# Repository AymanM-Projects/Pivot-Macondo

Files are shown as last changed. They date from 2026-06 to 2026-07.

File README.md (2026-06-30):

# Pivot-Macondo

What I created is a motorized mount that holds my friend's camera on a tripod so a person standing far away can point it, zoom it, and hit record all wirelessly from a controller, without ever touching the camera.

The reason I actually started this project is that I really wanted to create something with new CAD and coding skulls and really start using these skills to create  something meaningful, but  why I decided to create this mount specifically is for my childhood friend. I've known him for ten years. He's grown this passion for  cameras, photography, and videography, and I have noticed how he has enjoyed it when he does it. He uses cameras to make stories, to help people, we do advocacy. I thought it would be amazing for me and him to combine our talents and our passions, because I want to do the same thing.

What really matters to me is that I can actually use what I'm good at to create something with strength behind it. I want to create, I love making things, not just for myself, and not for money, but things that actually matter to people and make a real difference in their lives. I don't want anything in return for this. I just want to see people happy.

And I don't want this to be the end, I want it to be the start. Creativity can go a lot of ways. For me it's coding and hardware. But not just making things,  making new inventions. Creating products. Not just products, but inventions and innovations that change people's lives. That's why I'm starting here, with something I have a real passion to work on. I saw this kind of technology  and I knew I could make it the moment I saw it.

For the actual technical components I used **Onshape** for modeling and my **Bambu P2S** for test prints.

The mount contains 3 main components:
1. A Panning mechanism powered by a nema 17 stepper motor that is at the bottom and will rotate the hole mount 360 degrees 
2. A tilting mechanism that uses another nema 17 but also a bearing and a metal rod that goes through the drive and idle arms, it should rotate the entire camera cage 90 degrees vertically.
3. Lastly a zoom feature that works with a Pinion Motor gear  and a focus ring and a 28BYJ-48  for zooming the camera

Some additional things:
-  Through this project I learned a lot about clearance and how 3dc printing warps holes Before I thought you could design with exact parameters for each design but now i realize that you need to add clearance values for certain structures/features
- I learned what a driver is and how it works with a stepper motor
- I learned how to do torque math, for my two spinning motors(pan/tilt)

Things I want to do in the future:
- Right now It only fits my friends camera and fits for his tripod but i want to make it so it is like a phone holder and you can basically connect it to any camera through a slider or springs
- I want to add a way for users to make it go horizontal and vertical on a slider with a another motor because i feel this can be more useful
- I want to try using more gears or getting the price down for future builds
- 
## BOM

| Subsystem | Item | Purpose | Price | Source |
| --- | --- | --- | --- | --- |
| Pan mechanism | Lazy Susan Bearing 4 inch | Carries the rotating pan load (bearing takes the weight, not the motor shaft) | $4.99 | [Amazon](https://www.amazon.com/Turntable-Bearing-Rotating-Cabinet-Profile/dp/B09V2S71J1) |
| Pan mechanism | TMC2209 V1.3 Stepper Motor Driver (6-pack) | Drives a stepper motor quietly with current control | $29.99 | [Amazon](https://www.amazon.com/BIGTREETECH-Direct-TMC2209-Stepper-Control/dp/B08WZFK9KT) |
| Pan mechanism | NEMA 17 Stepper Motor (MAKERELE, 42-40mm) | Direct-drive pan axis rotation | $12.99 | [Amazon](https://www.amazon.com/MAKERELE-Stepper-42-48mm-Connector-Printers/dp/B0FP1QQ1NT) |
| Tilt mechanism | NEMA 17 Stepper Motor L=39mm 10:1 Planetary Gearbox | Geared tilt axis drive (holds the camera against gravity) | $37.99 | [Amazon](https://www.amazon.com/STEPPERONLINE-Nema-Stepper-Motor-Ratio/dp/B0F4CKD1VC) |
| Tilt mechanism | 608ZZ Ball Bearing (10 pcs) | Supports the tilt pivot shaft | $4.87 | [Amazon](https://www.amazon.com/Bearings-Double-Shielded-Miniature-Skateboard/dp/B07H83VV6B) |
| Tilt mechanism | 8mm dia 300mm 304 SS Round Rod (2 pcs) | Tilt pivot shaft + zoom support rod (cut to length) | $11.99 | [Amazon](https://www.amazon.com/Etauwe-Diameter-Length-Stainless-Working/dp/B0G78Y8HB4) |
| Tilt mechanism | 8mm Shaft Lock Collar (10 pcs) | Locks shafts axially in place | $8.89 | [Amazon](https://www.amazon.com/Zeberoxyz-Stainless-Material-Isolation-Accessories/dp/B08SK2LNNV) |
| Zoom mechanism | M3 M4 M5 Screws & Nuts Assortment Kit (460 pcs) | General fasteners across all assemblies | $13.49 | [Amazon](https://www.amazon.com/Hilitchi-510pcs-Stainless-Socket-Assortment/dp/B06XRFKNPQ) |
| Zoom mechanism | 0.8M 5mm Pinion Motor Gear 11T (3 pcs) | Steel pinion meshes with the lens gear ring to drive zoom | $9.99 | [Amazon](https://www.amazon.com/Fraizoe-RC-0-8M-5mm-3Pcs/dp/B0DYK2Z85B) |
| Zoom mechanism | 28BYJ-48 ULN2003 5V Stepper Motor (5 sets) | Drives the zoom ring with repeatable position | $14.99 | [Amazon](https://www.amazon.com/ELEGOO-28BYJ-48-ULN2003-Stepper-Arduino/dp/B01CP18J4A) |
| Zoom mechanism | SmallRig Seamless Gear Ring (72mm–74mm) | Rubber gear ring grips lens zoom barrel (removable, no marring) | $2.99 | [Amazon](https://www.amazon.com/SmallRig-Seamless-Focus-Gear-Ring/dp/B0986XSTP4) |
| Battery/wiring | AITRIP ESP32 30-pin USB-C (3-pack + expansion boards) | Microcontrollers for mount + controller (ESP-NOW link) | $9.99 | [Amazon](https://www.amazon.com/dp/B0B82CKB1K) |
| Battery/wiring | Anker Nano Power Bank 10000mAh 30W | Portable power source for the mount | $49.99 | [Amazon](https://www.amazon.com/Anker-Portable-Charger-Compatible-MacBook/dp/B0C9CJKCH3) |
| Battery/wiring | ACEIRMC ZY12PDN PD Trigger (2-pack screw terminals) | Pulls fixed 12V from the bank for the stepper rail | $14.99 | [Amazon](https://www.amazon.com/dp/B0CNVQMP6C) |
| Prototyping | ELEGOO 830-Point Solderless Breadboard (3 pcs) | Solderless prototyping of control/trigger circuits | $8.99 | [Amazon](https://www.amazon.com/EL-CP-003-Breadboard-Solderless-Distribution-Connecting/dp/B01EV6LJ7G) |
| Prototyping | ELEGOO 120pc Dupont Jumper Wires (M/M + M/F + F/F) | Breadboard interconnects in all three pin genders | $6.98 | [Amazon](https://www.amazon.com/Elegoo-EL-CP-004-Multicolored-Breadboard-arduino/dp/B01EV70C78) |
| Camera trigger | NOYITO PC817 1-Channel Optocoupler Module (screw terminals; 2-pack) | Isolated shutter signal, no electrical connection to the borrowed camera | $6.99 | [Amazon](https://www.amazon.com/NOYITO-1-Channel-Optocoupler-Optoelectronic-Anti-Interference/dp/B0B537T73S) |
| Camera trigger | CablesOnline 2.5mm TRS Male to 3-Pole Screw Terminal Connector (5-pack) | Plugs into S5ii remote port for shutter/record (verify pinout before wiring) | $16.95 | [Amazon](https://www.amazon.com/CablesOnline-3-Screw-Terminal-Connectors-PL-CN22-5/dp/B01J4JLP6K) |
| Power/filtering | ALLECIN 24-Value Electrolytic Capacitor Assortment Kit | Incl. 100uF/220uF/470uF — one cap across each driver VM absorbs spikes | $9.99 | [Amazon](https://www.amazon.com/ALLECIN-Electrolytic-Capacitor-Assortment-Kit/dp/B0C1VBXCQM) |
| Control input | 8BitDo SN30 Pro Bluetooth Gamepad | Bluepad32-compatible name-brand controller for the gamepad path | $44.99 | [Amazon](https://www.amazon.com/Bluetooth-Controller-Compatible-Raspberry-Gaming-Console/dp/B0CSP6TTJJ) |
| Filament | Black PETG Filament (1kg spool) | Structural printed parts (brackets, cradle, column) | $19.00 | [Bambu Lab](https://us.store.bambulab.com/products/petg-hf) |
| Tools | Onshape | CAD modeling | Owned (free) | |
| Tools | Bambu P2S 3D Printer | Manufactures the printed parts | Owned | |
| Tools | Arca Quick-Release Clamp | Tripod connection (already owned) | Owned | |
| ------------- | ------------- | ------------- | ------------- | ------------- |
| | | | | **Total: $342.03** |

# CAD
The link to my onshape document: https://cad.onshape.com/documents/704bc5fe6bc4690c89ce2bf7/w/60606dae933200bf2d7a1e9c/e/83d6a801d920139ae14113a5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

### Individual Parts:
quick release clamp(for connecting to the camera cage)



panning mechnism(connects to tripod and holds motor)



holder for camera cage w motor box for tilt motor


zoom(holder for the zoom motor and pinion gear to connect to the rest of the mount)



### Assembly 



## What's in this repo
- [CAD — my designed parts (STEP files)](cad/My_parts)
- [CAD — imported reference models + GrabCAD links](cad/Imports/intro.md)
- [Wiring diagram (EasyEDA)](Electronics/wiringdiagram.md)
- [Bill of Materials](BOM.csv)

Refrence(inspiration):https://github.com/geg-tech/biblicallyaccuratekeyboard/blob/main/README.md - I liked the format and the friendly tone,

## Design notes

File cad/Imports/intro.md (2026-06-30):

# Imported Parts (GrabCAD)

Here are all the GrabCAD models I used in my Onshape assembly. **None of these are my own designs** they're off-the-shelf parts I downloaded only as reference, so I could model and fit my own printed parts around them. Full credit goes to the original GrabCAD creators.

## Pan mechanism

- **Lazy Susan bearing (4"):** https://grabcad.com/library/4-inch-lazy-susan-turntable-steel-ball-bearing-rotating-tray-table-1
- **NEMA 17 stepper motor (pan axis):** https://grabcad.com/library/steeper-motor-nema-17-1

## Tilt mechanism

- **NEMA 17 stepper + 10:1 planetary gearbox (tilt axis):** https://www.omc-stepperonline.com/mg-series-planetary-gearbox-gear-ratio-10-1-backlash-30-arc-min-for-nema-17-stepper-motor-mg17-g10
- **608ZZ ball bearing:** https://grabcad.com/library/608zz-bearing-cad-model-with-exploded-assembly-and-technical-drawing-1
- **8mm shaft lock collar:** https://grabcad.com/library/8mm-internal-diameter-shaft-collar-lock-collar-1

## Zoom mechanism

- **28BYJ-48 stepper motor:** https://grabcad.com/library/28byj-48-8

## Other (not GrabCAD)
- **1/4-20 tripod nut/screw (tripod connector)** — from Cults3D: https://cults3d.com/en/3d-model/gadget/1-4-20-nut-screw-for-photo-camera-mount

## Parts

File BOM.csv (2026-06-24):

Subsystem | Item | Purpose | Qty | Price (USD) | Source
Pan mechanism | Lazy Susan Bearing 4 inch | Carries the rotating pan load (bearing takes the weight not the motor shaft) | 1 | 4.99 | https://www.amazon.com/Turntable-Bearing-Rotating-Cabinet-Profile/dp/B09V2S71J1
Pan mechanism | TMC2209 V1.3 Stepper Motor Driver (6-pack) | Drives a stepper motor quietly with current control | 1 | 29.99 | https://www.amazon.com/BIGTREETECH-Direct-TMC2209-Stepper-Control/dp/B08WZFK9KT
Pan mechanism | NEMA 17 Stepper Motor (MAKERELE 42-40mm) | Direct-drive pan axis rotation | 1 | 12.99 | https://www.amazon.com/MAKERELE-Stepper-42-48mm-Connector-Printers/dp/B0FP1QQ1NT
Tilt mechanism | NEMA 17 Stepper Motor L=39mm 10:1 Planetary Gearbox | Geared tilt axis drive (holds the camera against gravity) | 1 | 37.99 | https://www.amazon.com/STEPPERONLINE-Nema-Stepper-Motor-Ratio/dp/B0F4CKD1VC
Tilt mechanism | 608ZZ Ball Bearing (10 pcs) | Supports the tilt pivot shaft | 1 | 4.87 | https://www.amazon.com/Bearings-Double-Shielded-Miniature-Skateboard/dp/B07H83VV6B
Tilt mechanism | 8mm dia 300mm 304 SS Round Rod (2 pcs) | Tilt pivot shaft + zoom support rod (cut to length) | 1 | 11.99 | https://www.amazon.com/Etauwe-Diameter-Length-Stainless-Working/dp/B0G78Y8HB4
Tilt mechanism | 8mm Shaft Lock Collar (10 pcs) | Locks shafts axially in place | 1 | 8.89 | https://www.amazon.com/Zeberoxyz-Stainless-Material-Isolation-Accessories/dp/B08SK2LNNV
Zoom mechanism | M3 M4 M5 Screws & Nuts Assortment Kit (460 pcs) | General fasteners across all assemblies | 1 | 13.49 | https://www.amazon.com/Hilitchi-510pcs-Stainless-Socket-Assortment/dp/B06XRFKNPQ
Zoom mechanism | 0.8M 5mm Pinion Motor Gear 11T (3 pcs) | Steel pinion meshes with the lens gear ring to drive zoom | 1 | 9.99 | https://www.amazon.com/Fraizoe-RC-0-8M-5mm-3Pcs/dp/B0DYK2Z85B
Zoom mechanism | 28BYJ-48 ULN2003 5V Stepper Motor (5 sets) | Drives the zoom ring with repeatable position | 1 | 14.99 | https://www.amazon.com/ELEGOO-28BYJ-48-ULN2003-Stepper-Arduino/dp/B01CP18J4A
Zoom mechanism | SmallRig Seamless Gear Ring (72mm-74mm) | Rubber gear ring grips lens zoom barrel (removable no marring) | 1 | 2.99 | https://www.amazon.com/SmallRig-Seamless-Focus-Gear-Ring/dp/B0986XSTP4
Battery/wiring | AITRIP ESP32 30-pin USB-C (3-pack + expansion boards) | Microcontrollers for mount + controller (ESP-NOW link) | 1 | 9.99 | https://www.amazon.com/dp/B0B82CKB1K
Battery/wiring | Anker Nano Power Bank 10000mAh 30W | Portable power source for the mount | 1 | 49.99 | https://www.amazon.com/Anker-Portable-Charger-Compatible-MacBook/dp/B0C9CJKCH3
Battery/wiring | ACEIRMC ZY12PDN PD Trigger (2-pack screw terminals) | Pulls fixed 12V from the bank for the stepper rail | 1 | 14.99 | https://www.amazon.com/dp/B0CNVQMP6C
Prototyping | ELEGOO 830-Point Solderless Breadboard (3 pcs) | Solderless prototyping of control/trigger circuits | 1 | 8.99 | https://www.amazon.com/EL-CP-003-Breadboard-Solderless-Distribution-Connecting/dp/B01EV6LJ7G
Prototyping | ELEGOO 120pc Dupont Jumper Wires (M/M + M/F + F/F) | Breadboard interconnects in all three pin genders | 1 | 6.98 | https://www.amazon.com/Elegoo-EL-CP-004-Multicolored-Breadboard-arduino/dp/B01EV70C78
Camera trigger | NOYITO PC817 1-Channel Optocoupler Module (screw terminals; 2-pack) | Isolated shutter signal no electrical connection to the borrowed camera | 1 | 6.99 | https://www.amazon.com/NOYITO-1-Channel-Optocoupler-Optoelectronic-Anti-Interference/dp/B0B537T73S
Camera trigger | CablesOnline 2.5mm TRS Male to 3-Pole Screw Terminal Connector (5-pack) | Plugs into S5ii remote port for shutter/record (verify pinout before wiring) | 1 | 16.95 | https://www.amazon.com/CablesOnline-3-Screw-Terminal-Connectors-PL-CN22-5/dp/B01J4JLP6K
Power/filtering | ALLECIN 24-Value Electrolytic Capacitor Assortment Kit | Incl. 100uF/220uF/470uF - one cap across each driver VM absorbs spikes | 1 | 9.99 | https://www.amazon.com/ALLECIN-Electrolytic-Capacitor-Assortment-Kit/dp/B0C1VBXCQM
Control input | 8BitDo SN30 Pro Bluetooth Gamepad | Bluepad32-compatible name-brand controller for the gamepad path | 1 | 44.99 | https://www.amazon.com/Bluetooth-Controller-Compatible-Raspberry-Gaming-Console/dp/B0CSP6TTJJ
Filament | Black PETG Filament (1kg spool) | Structural printed parts (brackets cradle column) | 1 | 19.00 | https://us.store.bambulab.com/products/petg-hf
Tools | Onshape | CAD modeling | 1 | 0.00 | https://www.onshape.com
Tools | Bambu P2S 3D Printer | Manufactures the printed parts | 1 | 0.00 | (owned)
Tools | Arca Quick-Release Clamp | Tripod connection (already owned) | 1 | 0.00 | (owned)
 |  |  |  | TOTAL | 342.03

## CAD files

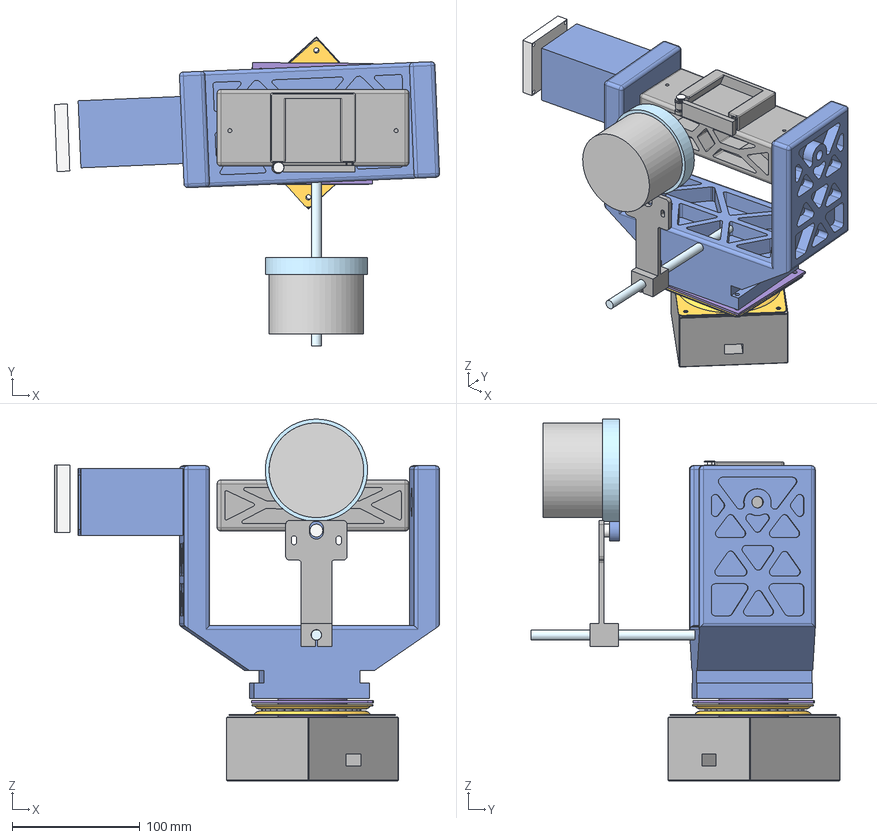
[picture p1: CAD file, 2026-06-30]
cad/My_parts/Full assembly.step
301.1 x 241.4 x 282.9 mm
steppers x 2
6mmBearing x 30
HalfLazySusan x 2

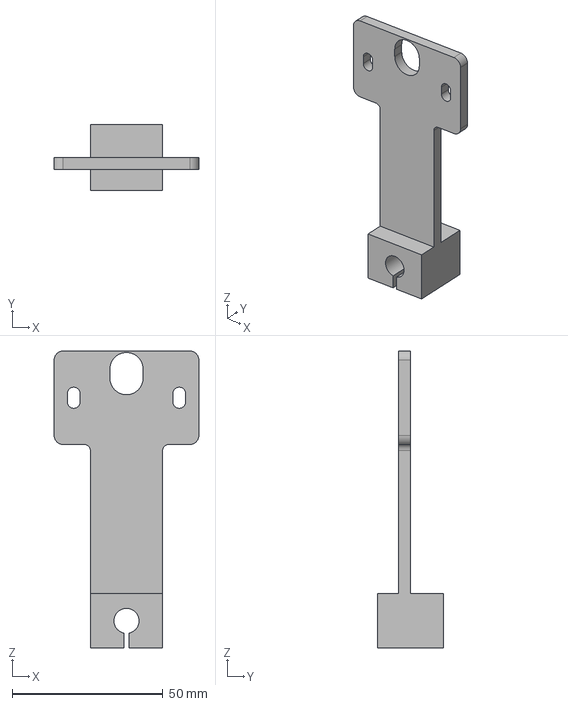
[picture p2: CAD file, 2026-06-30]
cad/My_parts/zoom connector.step
48.0 x 22.0 x 98.5 mm

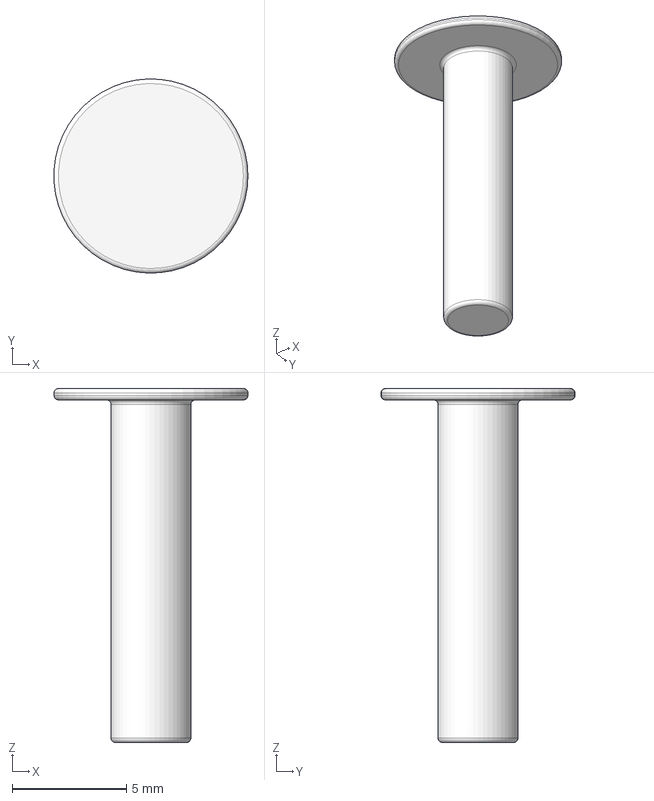
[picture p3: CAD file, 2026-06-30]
cad/My_parts/Quick Release Clamp Pin.step
8.49 x 8.50 x 15.5 mm

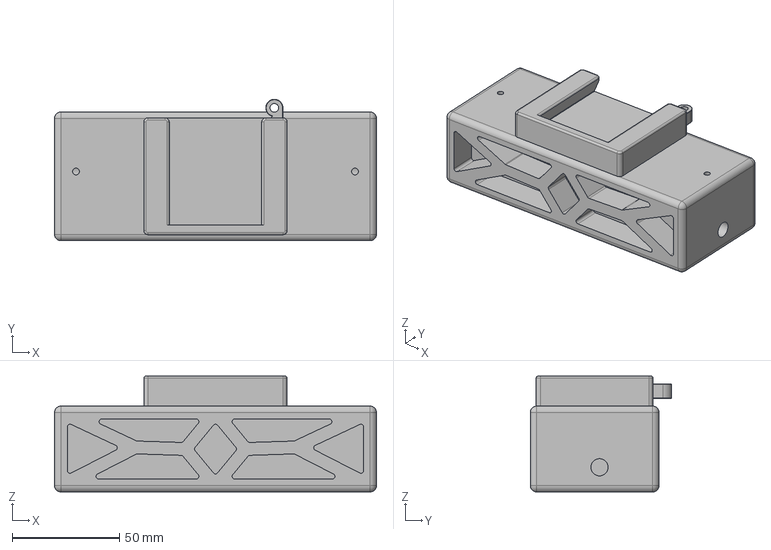
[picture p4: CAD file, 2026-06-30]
cad/My_parts/y comb quick release clamp.step
150.0 x 65.9 x 54.0 mm

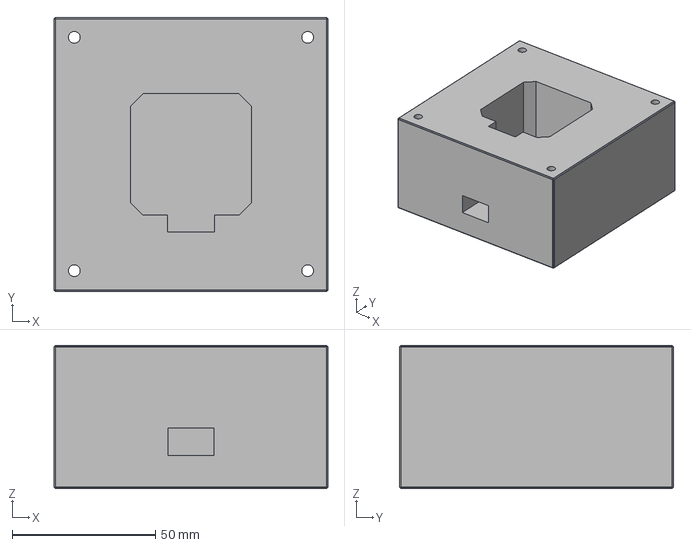
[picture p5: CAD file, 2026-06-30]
cad/My_parts/Tripod Connector Base.step
95.5 x 95.5 x 50.0 mm

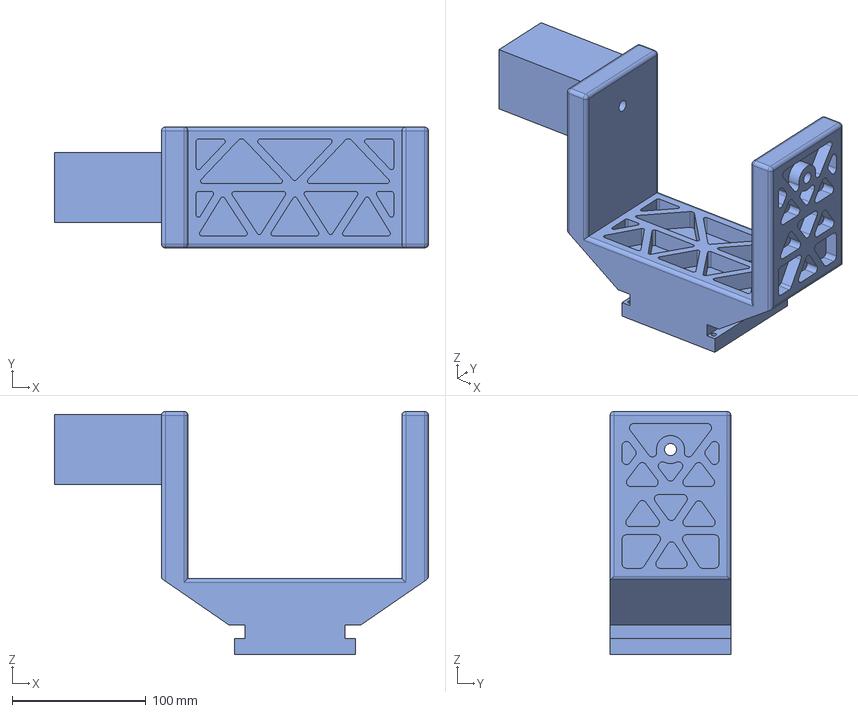
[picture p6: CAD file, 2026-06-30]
cad/My_parts/y comb Base.step
280.0 x 90.5 x 182.0 mm

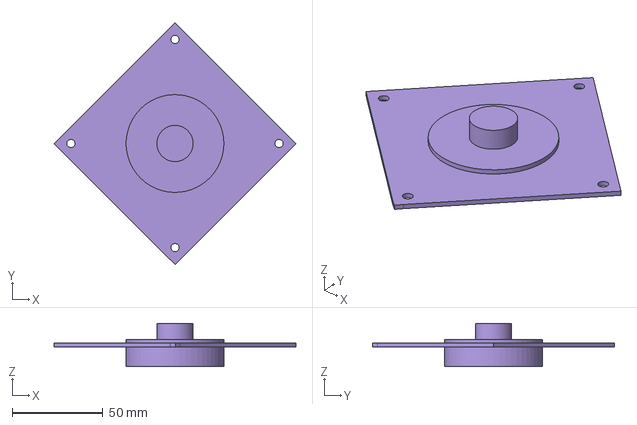
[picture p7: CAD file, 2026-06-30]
cad/My_parts/Tripod Connector Lazy Susan Connector.step
133.6 x 133.6 x 24.0 mm

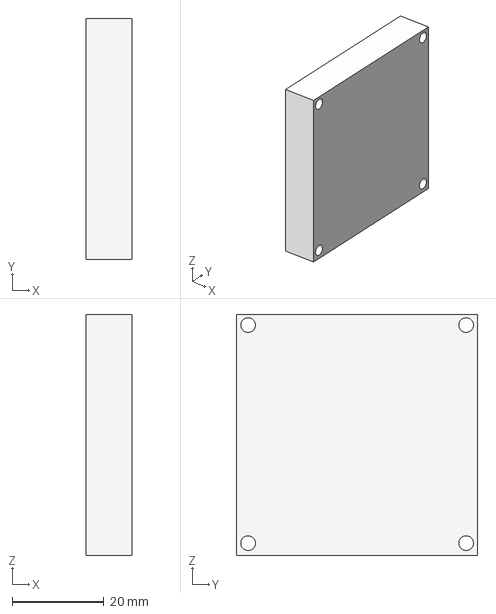
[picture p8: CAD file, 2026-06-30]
cad/My_parts/y comb lid.step
10.0 x 52.5 x 52.5 mm

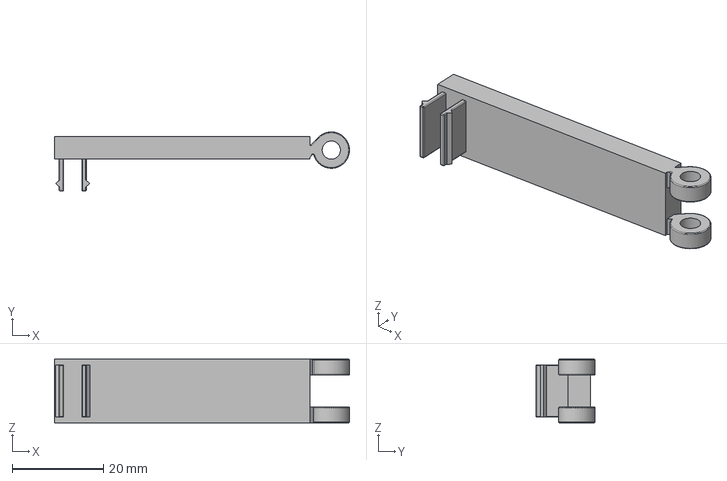
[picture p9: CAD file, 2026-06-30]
cad/My_parts/Quick Release clamp hinge.step
64.8 x 13.0 x 14.0 mm

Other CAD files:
cad/My_parts/Quick Release Clamp Hinge.stl
cad/My_parts/Quick Release Clamp Pin.stl
cad/My_parts/Tripod Connector Lazy Susan Connector.stl
cad/My_parts/tripod connector base.stl
cad/My_parts/y comb Base.stl
cad/My_parts/y comb lid.stl
cad/My_parts/y comb quick release clamp.stl
cad/My_parts/zoom connector.stl

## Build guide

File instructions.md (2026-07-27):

# Pivot — Build & Assembly Instructions

Hi guys here are general assembly instructions but also linked below is a assembly timelapse (pictures included) in assembly instruction

---

## 1. What you need/materials

### Tools
- 3D printer (I printed with a Bambulab 2 and engineering plate) + PETG filament (any color works, I also specified where you can use PLA and the cost of each print plate)
- Soldering iron, solder, heat shrink
- Metric hex keys, small screwdrivers
- Multimeter
- all the parts listed in the BOM, listed below

---

## 2. Print the parts

All custom parts are STEP files in [`My_parts/`](./My_parts/). Imported models (with credits) are listed in [`Imports/intro.md`](./Imports/intro.md).

- Material: PETG for everything structural/PLA when specified
- Layer height / infill / orientation per part: **[FILL IN — table of each part with print settings and orientation]**
- Parts use triangular truss pocketing printed flat-side-down, apex-up
- The electronics box has no pocketing on purpose

Print pics: one of each build plate with Bambulab settings :

1.
2.
3.
4.
5.
etc

---

## 3. Mechanical assembly :after you finished prints and they look liek pics/also pictures willbe provided for every part of the process once built.

### 3.1 Pan base
1. Bolt the lazy Susan bearing between the tripod base plate and the pan platform. ""need to add bolt sizes"
2. Mount the pan NEMA 17 in the column. **havent fully finished the fastener**
3. The base mounts to any standard tripod via the 1/4"-20 thread.

### 3.2 Tilt yoke
1. Assemble the yoke arms onto the pan platform.
2. Mount the tilt NEMA 17 + planetary gearbox on the drive side.
3. Set the camera cradle so the tilt pivot passes through the camera's center of gravity. 
4. Sweep tilt ±45° by hand and check nothing collides before wiring the motor. **this is just for testing**

### 3.3 Zoom drive
1. Wrap the SmallRig 3293 gear ring around the lens zoom ring. Friction fit only.
2. Measure the installed ring OD before trusting the bracket spacing (center distance is ~46.8 mm provisional).
3. Fix the 19T steel pinion on the 28BYJ-48 shaft (set screw on the flat).
4. Mount the zoom bracket and use the vertical slots (±1.5 mm) to set gear mesh: snug, no binding, no skipping. The rubber ring slipping under overload is intentional — it's the torque fuse.

### 3.4 Camera
Camera mounts by its 1/4"-20 socket into the cradle. **[FILL IN — cage/cradle attachment details]** No clamps or adhesives on the camera or lens; everything must come off without a mark.

---

## 4. Electronics

The full schematic is in the repo (EasyEDA export). **its in electronics folder in the repo**

### 4.1 Power
- USB-C PD port → ZY12PDN trigger fixed at **12 V** → stepper motor rail
- USB-A port → **5 V** → ESP32 and logic
- All grounds common
- Budget: ~19 W peak, ~8.5 W average, ~3 h runtime on the 10,000 mAh bank
- Never wire a motor directly to an ESP32 pin — everything goes through its driver

### 4.2 Wiring table
The wiring diagram is here(also located in electronics/wiringdiagram.md):

### 4.3 Camera trigger — read this before connecting anything
The S5II remote port is **not** a simple switch closure. It expects ~2 kΩ across the line for shutter and ~5 kΩ for focus. The PC817 optocoupler module isolates the camera from the ESP32; its VCC pin is left unconnected on purpose. **[VERIFY resistor values against a trusted Panasonic pinout source before first connection — wrong wiring can damage the camera.]** Test the trigger circuit with a multimeter before the 2.5 mm plug ever goes into the camera.

---

## 5. Firmware

- Platform: Arduino IDE, ESP32 board package, plain Arduino C++
- Two sketches: mount side and controller side, linked by ESP-NOW (peer-to-peer, no router)
- Flash each board over USB-C. **[FILL IN — board selection settings, MAC address pairing steps]**
- Position tracking is step-counted with firmware soft limits (no hard stops on the zoom ring)
- On startup the zoom axis runs a homing routine. **[FILL IN — homing procedure]**

---

## 6. First power-up checklist

1. Power the mount with **no camera installed**.
2. Verify 12 V on the stepper rail and 5 V on logic with a multimeter.
3. Test each axis individually from the controller: pan, tilt, zoom.
4. Verify trigger output resistance with a multimeter.
5. Only then install the camera and connect the 2.5 mm plug.

---

## 7. Troubleshooting

| Symptom | Check |
|---|---|
| Steppers hum but don't turn | Driver current setting, STEP/DIR wiring swapped |
| Zoom ring skips | Gear mesh too loose — adjust bracket slots |
| Zoom ring stalls lens | Mesh too tight, or hitting soft limit |
| No wireless link | ESP-NOW MAC addresses paired correctly, both boards powered |
| Camera won't trigger | Resistor values, TRS plug fully seated, correct 2.5 mm 3-pole part |

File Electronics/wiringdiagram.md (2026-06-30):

Here is my wiring diagram that I made in EasyEDA. The ESP32 sits in the center and acts as the brain of the whole thing. It connects out to the motor drivers and the camera, so every axis and the shutter all run off this one board.

For pan and tilt, the ESP32 drives two stepper drivers, and each driver runs its own NEMA-17 motor. The driver sits between the ESP32 and the motor because the ESP32 pins can only push a tiny bit of current, nowhere near enough to move a stepper, so the driver does the heavy lifting and the ESP32 just tells it when to step and which direction.

The zoom uses a different driver-motor module (the 28BYJ-48 with its ULN2003 board) since it's a smaller geared motor and doesn't need the bigger stepper drivers the pan and tilt use.

The shutter trigger goes through an optocoupler so the camera stays electrically isolated from the rest of the build. The ESP32 signal pin lights the LED side of the optocoupler, and the output side closes the connection to the camera's 2.5mm port through a 2kΩ resistor, which is the value Panasonic needs to register a shutter press.

Full wiring diagram from EasyEDA. ESP32 in the center driving pan and tilt (NEMA-17 steppers via their drivers), the zoom motor through its own driver module, and the camera shutter through an isolated optocoupler.

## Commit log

2026-06-22 Update README.md
    added BOM
2026-06-26 Create wiring diagram
2026-06-28 Update and rename wiring diagram to wiringdiagram.md
2026-06-30 add step
    [Full assembly.step]
2026-06-30 Create intro.md for imported parts documentation
    Added a markdown file listing imported parts used in the Onshape assembly, including links to GrabCAD models and other sources.
2026-07-27 Add build and assembly instructions for Pivot mount
    Added detailed build and assembly instructions for the Pivot motorized PTZ mount, including tools, parts, assembly steps, electronics, firmware, and troubleshooting.
2026-07-27 Revise assembly instructions and parts list
    Updated assembly instructions with material details and clarified parts list. Added assembly timelapse reference and adjusted print settings.
2026-07-27 Revise assembly and electronics instructions
    Updated instructions for mechanical assembly, electronics, and wiring. Added clarifications and notes for various steps.
2026-07-27 Fix formatting and clarify assembly instructions
    Correct formatting and clarify instructions in the assembly section. Update wiring diagram reference for better clarity.
